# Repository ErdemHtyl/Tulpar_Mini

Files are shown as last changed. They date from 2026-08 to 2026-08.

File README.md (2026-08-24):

# MiniTULPAR — Custom Flight Controller Board (FCB)

> A quadcopter flight controller designed from scratch around the STM32F405.
> Schematic, 4-layer PCB, power architecture, sensor integration and firmware
> all live in this repository — no existing open-source flight controller is
> used.

<p align="left">
  
  
  
  
  
</p>

---

## ⚠️ Project Status

This project is **under active development**. The table below shows what is
finished and what is still in progress:

| Component | Status | Notes |
|---|---|---|
| Schematic design | ✅ Rev A complete | `MiniTulpar_Schematic.pdf` |
| PCB layout (4 layer) | ✅ Complete | 53.6 × 53.6 mm, 1.6 mm |
| Manufacturing files (Gerber/BOM/CPL) | ✅ Generated | `mfr/` |
| System architecture documentation | ✅ Complete | `docs/architecture.md` |
| Pin configuration (CubeMX) | ✅ Verified | No timer channel conflicts |
| Clock tree configuration | ✅ Verified | 168 MHz SYSCLK, 48 MHz USB |
| Board fabrication and assembly | 🔄 Planned | — |
| **Firmware** | 🚧 **In development — not started** | See the roadmap below |
| Flight testing | ⏳ Blocked | Depends on firmware |
| Lower-cost board variants | 🔄 Planned | See [Planned Variants](#planned-variants) |

> **Firmware note:** the firmware is **in development**. Nothing described in
> the roadmap below has been implemented yet — drivers, sensor fusion, PID
> control and the safety layer are all still to be written. The architectural
> decisions behind them (bus allocation, timer/DMA assignments, interrupt
> priorities) are documented in advance in `docs/architecture.md`, and
> development will follow that document. **The board does not fly in its
> current state.**

---

## Table of Contents

- [Project Goal](#project-goal)
- [Hardware Overview](#hardware-overview)
- [System Architecture](#system-architecture)
- [Bus Allocation and Rationale](#bus-allocation-and-rationale)
- [Timer and DMA Allocation](#timer-and-dma-allocation)
- [Pin Map](#pin-map)
- [Clock Configuration](#clock-configuration)
- [Firmware Roadmap](#firmware-roadmap)
- [Planned Variants](#planned-variants)
- [Repository Layout](#repository-layout)
- [Development Environment](#development-environment)
- [Known Issues and Rev B Notes](#known-issues-and-rev-b-notes)
- [License](#license)

---

## Project Goal

The goal is to **design, understand and implement every hardware and software
component** rather than buying an off-the-shelf flight controller (Betaflight /
ArduPilot hardware). That includes:

- Multi-layer PCB design and power architecture
- Writing IMU / barometer / magnetometer drivers from scratch
- Sensor fusion (Mahony / Madgwick / EKF)
- PID-based stabilisation and mixing
- Generating the DShot ESC protocol directly from timers and DMA
- GPS, telemetry, blackbox logging and the failsafe/safety layer

Every design decision is recorded in `docs/architecture.md` together with the
alternative that was rejected and the reason it was rejected.

---

## Hardware Overview

| Feature | Value |
|---|---|
| MCU | **STM32F405RGT6** — Cortex-M4F, 168 MHz, 1 MB Flash, 192 KB RAM (128 KB SRAM + 64 KB CCM) |
| Oscillator | 8 MHz HSE (ECS-80-10-30B-CKM-TR) |
| PCB | 4 layer, 53.6 × 53.6 mm, 1.6 mm thickness |
| Power | USB-C 5 V ↔ VIN, Schottky OR (D2/D3) + JP1 jumper → **LD39200PU33R** 3.3 V / 2 A LDO |
| IMU | **ICM-42670-P** (accel + gyro) — SPI1 @ 21 MHz, INT1 → PC4 |
| Barometer | **BMP581** — I2C2, 0x46, INT → PB1 |
| Magnetometer | **IIS2MDC** — I2C2, 0x1E, DRDY → PB2 |
| Blackbox flash | **W25Q128JVS** 16 MB — SPI2 @ 21 MHz |
| Motor outputs | 4× **DShot600** — TIM8_CH1..CH4 (PC6–PC9), single DMA burst |
| Auxiliary PWM | TIM1_CH1/CH3 (PA8/PA10) + TIM3_CH1/CH2 (PB4/PB5 — camera gimbal) |
| RC input | CRSF / ELRS — UART4 (J10) |
| GPS | USART2 (J12) |
| Telemetry | UART5 (J11) |
| Spare UART | USART3 (J5) |
| External I²C | I2C1 (J6) — separate from the internal sensor bus |
| ADC | Battery voltage → PC3 (ADC1_IN13), external → PC2 (ADC1_IN12) |
| USB | USB-C 2.0, USBLC6-2SC6 ESD protection + polyfuse + 5.1 kΩ CC |
| Debug | 10-pin 1.27 mm SWD (J13) |
| LEDs | 3× status LEDs + power LED |

---

## System Architecture

```mermaid
flowchart TB
    subgraph PWR["Power Tree"]
        XT[["VIN / Rail"]]
        USB5[["USB-C 5 V"]]
        OR{{"D2 / D3 Schottky OR<br/>+ JP1"}}
        LDO["U1 LD39200PU33R<br/>3.3 V / 2 A"]
        XT --> OR
        USB5 --> OR
        OR --> LDO
        LDO --> V33[("+3.3 V")]
        LDO -. "FB1 600Ω@100MHz" .-> VDDA[("VDDA")]
    end

    subgraph MCU["STM32F405RGT6 @ 168 MHz"]
        CORE["Cortex-M4F<br/>FPU + DSP"]
    end

    subgraph FAST["High rate — SPI1 @ 21 MHz"]
        IMU["U2 ICM-42670-P<br/>CS = PA4 · INT1 → PC4"]
    end

    subgraph SLOW["Slow sensor bus — I2C2 @ 400 kHz"]
        BARO["U4 BMP581 · 0x46"]
        MAG["U6 IIS2MDC · 0x1E"]
    end

    subgraph LOG["Logging — SPI2 @ 21 MHz"]
        FLASH["U7 W25Q128JVS<br/>16 MB · CS = PB12"]
    end

    subgraph ACT["Actuators"]
        ESC["4× ESC · DShot600<br/>TIM8_CH1..CH4"]
        SERVO["Aux PWM · TIM1 / TIM3"]
    end

    subgraph COMM["Serial links"]
        RC["CRSF/RC · UART4"]
        GPS["GPS · USART2"]
        TLM["Telemetry · UART5"]
        AUX["Spare · USART3"]
        EXTI2C["External I2C1"]
    end

    V33 --> MCU
    IMU <-->|SPI1| CORE
    BARO <-->|I2C2| CORE
    MAG <-->|I2C2| CORE
    FLASH <-->|SPI2| CORE
    CORE --> ESC
    CORE --> SERVO
    RC <--> CORE
    GPS <--> CORE
    TLM <--> CORE
    AUX <--> CORE
    EXTI2C <--> CORE
```

**The critical data path:** the IMU's INT1 line raises an EXTI interrupt → a
SPI1 DMA burst read starts → the DMA completion interrupt runs the filter, PID
and mixer chain → the result is encoded into a DShot frame and handed to the
TIM8 DMA. The whole chain completes **inside one interrupt context**, never
waiting on any other peripheral.

---

## Bus Allocation and Rationale

The founding principle of the architecture:

> **The critical path lives on SPI. Everything non-critical lives on I²C.**

| Device | Bus | Speed | Why |
|---|---|---|---|
| ICM-42670-P | **SPI1** (alone) | 21 MHz | The only high-rate path; the same read takes ~68× longer on I²C |
| BMP581 + IIS2MDC | **I2C2** (shared) | 400 kHz | ~4 % combined bus load; neither is on the critical path |
| W25Q128JVS | **SPI2** (alone) | 21 MHz | A sector erase can take 400 ms and must never delay a gyro read |
| External devices | **I2C1** | 400 kHz | A cable means ESD, capacitance and lockup risk — isolated from the internal sensors |

**Why the IMU is on SPI.** A 15-byte sample read takes ~5.7 µs on SPI1 versus
~388 µs on I²C Fast-mode:

| Loop rate | SPI load | I²C load |
|---|---|---|
| 1 kHz | 0.6 % | 39 % |
| 1.6 kHz | 0.9 % | 62 % |
| 4 kHz | 2.3 % | impossible |

Beyond bandwidth: SPI is deterministic (no clock stretching), has no bus-lockup
failure mode, survives the noisy environment of ESCs switching at 20–40 kHz
thanks to its push-pull drivers, and costs the CPU nothing when paired with DMA.

---

## Timer and DMA Allocation

### Timer assignment

The current CubeMX pin configuration is **conflict-free** — all four motor
outputs, both auxiliary PWM channels and both gimbal channels are usable at the
same time:

| Function | Timer | Channel | Pin | Timer clock |
|---|---|---|---|---|
| Motor 1–4 | **TIM8** | CH1–CH4 | PC6 / PC7 / PC8 / PC9 | 168 MHz (APB2) |
| Aux PWM 1–2 | TIM1 | CH1 / CH3 | PA8 / PA10 | 168 MHz (APB2) |
| Camera gimbal 1–2 | TIM3 | CH2 / CH1 | PB5 / PB4 | 84 MHz (APB1) |

The motors are on **TIM8** rather than TIM3 for four reasons:

1. TIM3_CH1 can be routed to either PC6 or PB4, but only one at a time — putting
   the motors on TIM8 leaves TIM3 entirely free for the gimbal outputs.
2. TIM8 sits on APB2, so its timer clock is 168 MHz (twice TIM3's) — twice the
   DShot bit-timing resolution.
3. TIM8 is an advanced-control timer: its break input can drive a hardware motor
   cutoff for failsafe later.
4. All four motors on one timer are bit-synchronous and need only a single DMA
   burst (TIM8_UP + DMAR).

Because the two gimbal channels sit on TIM3 (84 MHz) and the aux PWM channels on
TIM1 (168 MHz), driving both at a common servo rate means programming the two
timers separately with different prescaler values.

### DShot600 timing (TIM8 @ 168 MHz)

| Protocol | ARR | CCR for "0" | CCR for "1" | Frame |
|---|---|---|---|---|
| DShot300 | 559 | 210 | 420 | 53.3 µs |
| **DShot600** | **279** | **105** | **210** | **26.7 µs** |

DShot is digital: **ESC calibration stops being a step that exists**, and every
frame carries a 4-bit CRC — a command corrupted by noise is discarded by the ESC
instead of silently applying the wrong throttle.

### DMA assignments (under the RM0090 Table 42/43 constraints)

**DMA2**

| Stream | Ch | Assignment |
|---|---|---|
| S0 | 3 | SPI1_RX — IMU read *(the critical path)* |
| S1 | 7 | TIM8_UP — DShot burst output |
| S5 | 3 | SPI1_TX — IMU command |
| S2/S3/S4/S7 | 7 | *Reserved:* bidirectional DShot (unused in v1) |

**DMA1**

| Stream | Ch | Assignment |
|---|---|---|
| S0 | 4 | UART5_RX — telemetry |
| S1 | 4 | USART3_RX — spare |
| S2 | 4 | UART4_RX — CRSF/RC *(420 kbaud, critical)* |
| S3 | 0 | SPI2_RX — flash |
| S4 | 0 | SPI2_TX — blackbox |
| S5 | 4 | USART2_RX — GPS (circular + IDLE) |
| S6 | 4 | USART2_TX — GPS configuration |
| S7 | 4 | UART5_TX — telemetry |

I2C1/I2C2, UART4_TX, USART3_TX and ADC1 are interrupt-driven — their streams
went to higher-value work and their load is negligible.

### Interrupt priorities (NVIC)

| Priority | Interrupt |
|---|---|
| 0 | EXTI4 — IMU INT1 (timestamps the sampling instant) |
| 1 | DMA2_S0 — SPI1_RX complete (triggers the control chain) |
| 2 | DMA2_S1 — TIM8_UP (motor frame) |
| 3 | DMA1_S2 — UART4_RX (RC / failsafe) |
| 4 | DMA1_S5 — USART2_RX (GPS) |
| 5 | I2C2_EV / I2C2_ER |
| 6 | SysTick |
| 7 | Flash, UART5, USB |

> **The rule:** blackbox writes, USB and telemetry must **never** preempt the
> control loop.

### Target timing budget (1 kHz loop)

| Step | Duration | Occupies the CPU? |
|---|---|---|
| IMU SPI burst read | 5.7 µs | No (DMA) |
| Filtering (3× biquad + PT1) | ~10 µs | Yes |
| Attitude update (Mahony) | ~20 µs | Yes |
| PID (3 axes) | ~12 µs | Yes |
| Mixer + motor limiting | ~4 µs | Yes |
| DShot frame encoding | ~6 µs | Yes |
| **Total CPU** | **~52 µs** | **≈ 5 % load** |

---

## Pin Map

This table is the single source of truth for the pin map — it is never
maintained in two places.

| Port | Signal | Function |
|---|---|---|
| PA4 / PA5 / PA6 / PA7 | SPI1 CS/SCK/MISO/MOSI | IMU |
| PC4 | INT_IMU1 | EXTI4 — data ready |
| PB12 / PB13 / PB14 / PB15 | SPI2 CS/SCK/MISO/MOSI | Blackbox flash |
| PB10 / PB11 | I2C2 SCL/SDA | Internal sensor bus |
| PB1 / PB2 | INT_BAR / INT_MAG | EXTI1 / EXTI2 |
| PB8 / PB9 | I2C1 SCL/SDA | External connector (J6) |
| PC6 / PC7 / PC8 / PC9 | DSHOT_1..4 | **TIM8_CH1..CH4** |
| PA8 / PA10 | Aux PWM 1–2 | TIM1_CH1 / TIM1_CH3 |
| PB4 / PB5 | CAM_GIMBAL2 / CAM_GIMBAL1 | TIM3_CH1 / TIM3_CH2 |
| PA0 / PA1 | UART4 TX/RX | CRSF / RC (J10) |
| PA2 / PA3 | USART2 TX/RX | GPS (J12) |
| PC12 / PD2 | UART5 TX/RX | Telemetry (J11) |
| PC10 / PC11 | USART3 TX/RX | Spare (J5) |
| PC2 / PC3 | ADC1_IN12 / ADC1_IN13 | External ADC / battery |
| PA11 / PA12 / PA9 | USB DM/DP/VBUS | USB-C |
| PA13 / PA14 | SWDIO / SWCLK | SWD (J13) |
| PC13 / PC14 / PC15 | LD1 / LD2 / LD3 | Status LEDs |
| PH0 / PH1 | HSE IN/OUT | 8 MHz crystal |

**Unused and available:** PA15, PB0, PB3, PB6, PB7, PC0, PC1, PC5.
PB6/PB7 = USART1, PB0/PB1 = TIM3_CH3/CH4, and PB0 + PC5 together are exactly the
chip select + interrupt pair a second IMU would need.

Full pin table including physical pin numbers: [`docs/architecture.md`](docs/architecture.md)

---

## Clock Configuration

8 MHz HSE crystal → PLL (M = 4, N = 168, P = 2) → **168 MHz SYSCLK**, with the
PLL Q divider set to 7 for the 48 MHz USB clock. CSS (clock security system) is
enabled, so a crystal failure falls back to the HSI instead of stopping the
core.

| Domain | Prescaler | Frequency |
|---|---|---|
| SYSCLK / HCLK (AHB, core, memory, DMA) | /1 | **168 MHz** |
| APB1 peripheral clock (PCLK1) | /4 | 42 MHz |
| APB1 timer clock (TIM3 …) | — | 84 MHz |
| APB2 peripheral clock (PCLK2) | /2 | 84 MHz |
| APB2 timer clock (**TIM1, TIM8**) | — | **168 MHz** |
| USB OTG FS | PLL /Q = 7 | 48 MHz |
| IWDG | LSI | 32 kHz |

The RTC runs from the internal LSI — no LSE crystal is fitted, because PC14/PC15
are used as status LED outputs. This is irrelevant for a flight controller.

SPI1 and SPI2 both run at 21 MHz: SPI1 from PCLK2 (84 MHz ÷ 4) and SPI2 from
PCLK1 (42 MHz ÷ 2), both comfortably under the ICM-42670-P's 24 MHz and the
W25Q128's 133 MHz limits.

---

## Firmware Roadmap

> 🚧 **Nothing in this section has been implemented yet.** The order is chosen to
> minimise bring-up risk; each step depends on the previous one being verified.

### Stage 0 — Bring-up
- [ ] Project skeleton and build system
- [ ] SWD connection and LED blink — is the board alive?
- [ ] Bring up the clock tree on hardware and measure it (8 MHz HSE → 168 MHz)
- [ ] Generate the pin configuration from the pin map above
- [ ] Debug console over USB CDC

### Stage 1 — Sensors
- [ ] SPI1 + DMA driver, ICM-42670-P WHO_AM_I
- [ ] Raw IMU reads (INT1 → EXTI → DMA burst chain)
- [ ] IMU internal UI filter / ODR configuration *(anti-aliasing is critical)*
- [ ] I2C2 as a **non-blocking state machine** + timeouts + bus recovery (9× SCL)
- [ ] BMP581 driver (pressure → altitude)
- [ ] IIS2MDC driver + hard/soft-iron calibration
- [ ] Gyro/accel calibration and temperature compensation

### Stage 2 — Actuators
- [ ] DShot600 frame generation via TIM8 + DMAR burst
- [ ] Motor test mode — **props off**, verify frames on a scope
- [ ] Mixer (quad X), motor limiting / airmode

### Stage 3 — Control
- [ ] Gyro filter chain (biquad LPF + notch + PT1)
- [ ] Attitude estimation — Mahony (EKF later)
- [ ] Rate PID loop (acro mode)
- [ ] Angle/horizon loop (self-level)
- [ ] PID gain tuning interface

### Stage 4 — RC and safety
- [ ] CRSF parser (UART4 DMA + IDLE line)
- [ ] Arming/disarming state machine + sensor health check
- [ ] **IWDG** (~50 ms, fed only by the main control loop)
- [ ] Gyro timeout → immediate disarm
- [ ] RC timeout (~500 ms) → progressive throttle-cut failsafe
- [ ] Battery voltage monitoring + low-voltage warning

### Stage 5 — Navigation and logging
- [ ] GPS UBX/NMEA parser (USART2 DMA)
- [ ] Blackbox logging (SPI2 → W25Q128, pre-erase while idle)
- [ ] Telemetry (UART5) and the CRSF back-channel
- [ ] Altitude hold → position hold → return-to-home

### Stage 6 — Advanced
- [ ] Bidirectional DShot (RPM telemetry) + RPM-based notch filtering
- [ ] EKF-based sensor fusion
- [ ] Host-side unit tests (HIL/SIL)

**The safety layer is non-negotiable:** motors are **always** disarmed at
power-up; arming requires low throttle plus an explicit arm command plus a
sensor health check.

---

## Planned Variants

MiniTULPAR Rev A is the reference design — it is deliberately built with
good parts rather than cheap ones, so that when something misbehaves the cause
is the design and not the bill of materials.

**More affordable versions of this board will be added later.** The plan is to
publish lower-cost variants alongside the reference design, so the project stays
buildable on a smaller budget:

- Cheaper sensor options (a lower-cost IMU and barometer in place of the
  ICM-42670-P / BMP581)
- A reduced-feature build — dropping the blackbox flash, the magnetometer or the
  gimbal outputs where they are not needed
- Widely stocked, low-cost alternatives for the passives, connectors and the
  regulator
- Where a substitution changes the firmware, the difference will be documented
  rather than hidden behind a build flag

Each variant will ship with its own BOM and a short note on what was traded
away. The reference design stays the one that is documented and tested first.

---

## Repository Layout

Hardware and firmware live in a **single repository** (monorepo) — when a pin
changes, KiCad, the documentation and the firmware are all updated in the same
commit.

```
custom-fcb/
├── README.md
├── docs/                    architecture, power tree, pinout, BOM, test plan
│   ├── architecture.md      design decisions and their rationale (EN)
│   └── images/
├── hardware/
│   ├── MiniTULPAR.kicad_pro / .kicad_sch / .kicad_pcb
│   ├── libs/                custom symbol + footprint libraries
│   ├── datasheets/
│   └── production/          Gerber / drill / BOM / CPL — gitignored
└── firmware/                🚧 in development — nothing implemented yet
    ├── drivers/             imu, baro, mag, gps, crsf, esc/dshot
    ├── fusion/              mahony / madgwick / ekf
    ├── control/             pid, rate and angle loops, mixer
    ├── telemetry/
    ├── safety/              failsafe, arming, watchdog
    └── tests/               host-side unit tests
```

**Version control rules**

- `hardware/production/` is gitignored. Gerbers are added by hand only when a
  board is ordered, together with `git tag hw-vX.Y` — so it is always certain
  which board was built from which files.
- Flight logs (`logs/`, `*.bbl`) never enter the repository.
- `.gitattributes` normalises line endings to LF in the repository.

---

## Development Environment

**Hardware side**

| Tool | Version / note |
|---|---|
| KiCad | 8.x |
| Schematic | `MiniTULPAR.kicad_sch` (+ `scheme_diagram.kicad_sch`) |
| Custom footprints | `ftp.pretty/` |
| Custom symbols | `MiniTULPAR_sym.kicad_sym` |

**Firmware side** *(planned)*

| Tool | Note |
|---|---|
| Toolchain | `arm-none-eabi-gcc` |
| Build | CMake + Ninja |
| Peripheral layer | STM32CubeF4 (mostly LL; register level on the critical path) |
| Pin & clock configuration | STM32CubeMX |
| Debug | ST-Link / J-Link + OpenOCD, SWO trace |
| Measurement | Loop-time profiling with the DWT cycle counter |

**Ordering a board**

```powershell
git tag -a hw-v0.1 -m "First board order"
git push --tags
gh release create hw-v0.1 hardware\production\*.zip
```

---

## Known Issues and Rev B Notes

Findings from the schematic review. **None of them makes the board
non-functional**, but they should be decided before fabrication.

| # | Issue | Status / recommendation |
|---|---|---|
| 1 | **ICM-42670-P ODR ceiling of 1.6 kHz** — this is the low-power member of the family, not the ICM-42688-P. An 8 kHz loop is **not possible** on this board (sensor-limited, not bus-limited). | Target a **1 kHz PID loop**. Because of the aliasing risk, the internal UI filter must be configured deliberately and the IMU soft-mounted. |
| 2 | **The battery divider is off-board**, with no overvoltage protection. | Rev B: 1 kΩ series into PC3 plus a Schottky clamp to 3.3 V. |
| 3 | **LDO thermal budget** — 0.85 W at 500 mA with 5 V in. J5/J6/J7/J10/J11/J12 all supply 3.3 V, and a GPS module alone can draw 100–150 mA. | Thermal via array under the LDO; the load budget belongs in `docs/power-tree.md`. |
| 4 | **DShot pins after reset** are high-impedance. | Confirm the ESCs do not apply throttle in that state; add pull-downs on the motor lines if they do (Rev B). |

---

## License

**BSD 3-Clause License** — Copyright © 2026 Erdem Hatayoğlu.

One licence covers the whole repository: firmware, hardware design files and
documentation. It is permissive — you may use, modify and redistribute this
work in source and binary form, including commercially and in closed-source
products, provided that:

- the copyright notice, the list of conditions and the disclaimer are retained
- neither the project name nor the author's name is used to endorse or promote
  derived products without prior written permission

The work comes with no warranty of any kind. Full text: [`LICENSE`](LICENSE)

New files should carry an SPDX header so each file's licence is unambiguous:

```
SPDX-License-Identifier: BSD-3-Clause
SPDX-FileCopyrightText: 2026 Erdem Hatayoğlu
```

Third-party files (vendor headers, generated peripheral libraries, imported
footprints) keep the licence of their original author; where such a file carries
its own licence header, that header takes precedence.

---

## Disclaimer

This board and its firmware are **in development and untested**. Spinning
propellers can cause serious injury. Always run motor tests **with the
propellers removed**, perform the first closed-loop attempts on a safe test
bench, and verify the arming and failsafe logic before flying. Use this project
entirely at your own risk.

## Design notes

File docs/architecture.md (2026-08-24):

# MiniTULPAR — System Architecture and Design Rationale

**Board:** MiniTULPAR FCB · **Schematic revision:** Rev A (2026-08-10) + updated CubeMX pin configuration
**MCU:** STM32F405RGT6 (LQFP64, 168 MHz, 1 MB Flash, 192 KB RAM)
**Document status:** Derived from the Rev A schematic and the current CubeMX pinout; firmware decisions are proposals.
**Location:** `docs/architecture.md`

> This document does not record *what* was built — it records **why it was built
> this way**. Every decision lists the alternative that was rejected and the
> reason it was rejected. When the board is revised, this document gets revised
> too. If the schematic and this document ever disagree, **the schematic is
> right and this document is wrong** — fix the document.

---

## 0. Executive summary — the architecture in three sentences

A single ICM-42670-P IMU sits alone on **SPI1** and is sampled on a data-ready
interrupt; this is the only high-rate path on the board and it gets a bus to
itself. Slow sensors — barometer and magnetometer — share **I2C2**, because
their sampling rates cannot stress the bus and sharing buys back pins. All four
motors are driven from **TIM8** over DShot through a single DMA stream (TIM8_UP
with DMAR burst), and everything else flows through UART/DMA pairs that never
touch the CPU.

---

## 1. Block diagram

```mermaid
flowchart TB
    subgraph PWR["Power Tree"]
        XT[["Rail / XT60<br/>VCC"]]
        USB5[["USB-C 5 V"]]
        OR{{"D2 / D3 Schottky OR<br/>+ JP1 jumper"}}
        LDO["U1 LD39200PU33R<br/>3.3 V / 2 A LDO"]
        XT --> OR
        USB5 --> OR
        OR --> LDO
        LDO --> V33[("+3.3 V")]
        LDO -. "FB1 600Ω@100MHz" .-> VDDA[("VDDA")]
    end

    subgraph MCU["STM32F405RGT6 @ 168 MHz — HSE 8 MHz (X1)"]
        CORE["Cortex-M4F<br/>FPU + DSP"]
    end

    subgraph FAST["High rate — SPI1 @ 21 MHz"]
        IMU["U2 ICM-42670-P<br/>Accel + Gyro<br/>CS = PA4<br/>INT1 → PC4"]
    end

    subgraph SLOW["Slow sensor bus — I2C2 @ 400 kHz"]
        BARO["U4 BMP581<br/>0x46 · INT → PB1"]
        MAG["U6 IIS2MDC<br/>0x1E · DRDY → PB2"]
    end

    subgraph LOG["Logging — SPI2 @ 21 MHz"]
        FLASH["U7 W25Q128JVS<br/>16 MB · CS = PB12"]
    end

    subgraph ACT["Actuators"]
        ESC["4× ESC · DShot600<br/>TIM8_CH1..CH4<br/>PC6 PC7 PC8 PC9"]
        SERVO["Aux PWM<br/>TIM1_CH1/CH3 · PA8 PA10<br/>Gimbal · PB4 PB5 (TIM3)"]
    end

    subgraph COMM["Serial links"]
        RC["J10 CRSF/RC<br/>UART4 · PA0/PA1"]
        GPS["J12 GPS<br/>USART2 · PA2/PA3"]
        TLM["J11 Telemetry<br/>UART5 · PC12/PD2"]
        AUX["J5 Spare UART<br/>USART3 · PC10/PC11"]
        EXTI2C["J6 External I2C1<br/>PB8/PB9"]
    end

    subgraph MISC["Other"]
        ADCIN["J7 ADC → PC2<br/>J8 Battery → PC3"]
        SWD["J13 SWD<br/>PA13/PA14"]
        USBP["USB-C · PA11/PA12<br/>USBLC6-2SC6 ESD"]
        LEDS["LD1..LD3<br/>PC13/PC14/PC15"]
    end

    V33 --> MCU
    IMU <-->|SPI1| CORE
    BARO <-->|I2C2| CORE
    MAG <-->|I2C2| CORE
    FLASH <-->|SPI2| CORE
    CORE --> ESC
    CORE --> SERVO
    RC <--> CORE
    GPS <--> CORE
    TLM <--> CORE
    AUX <--> CORE
    EXTI2C <--> CORE
    ADCIN --> CORE
    SWD <--> CORE
    USBP <--> CORE
    CORE --> LEDS
```

**How data actually flows:** the IMU's INT1 line raises an EXTI interrupt → a
SPI1 DMA burst read starts → the DMA completion interrupt runs the filter, PID
and mixer chain → the result is encoded into a DShot frame and handed to the
TIM8 DMA. The whole chain completes **inside one interrupt context**, never
waiting on any other peripheral. Everything else — baro, mag, GPS, telemetry,
logging — runs outside that chain at lower priority.

### 1.1 Complete pin assignment

STM32F405RGT6, LQFP64. This table is the intended single source of truth — the
firmware's `board.h` should be derived from it, not maintained in parallel.

| Pin | Port | Signal | Peripheral / alternate function |
|---|---|---|---|
| 20 | PA4 | SPI1_CS1 | GPIO output — IMU chip select |
| 21 | PA5 | SPI1_SCK | SPI1 |
| 22 | PA6 | SPI1_MISO | SPI1 |
| 23 | PA7 | SPI1_MOSI | SPI1 |
| 24 | PC4 | INT_IMU1 | EXTI4 — IMU data ready |
| 33 | PB12 | SPI2_CS | GPIO output — flash chip select |
| 34 | PB13 | SPI2_SCK | SPI2 |
| 35 | PB14 | SPI2_MISO | SPI2 |
| 36 | PB15 | SPI2_MOSI | SPI2 |
| 29 | PB10 | I2C2_SCL | I2C2 — internal sensor bus |
| 30 | PB11 | I2C2_SDA | I2C2 |
| 27 | PB1 | INT_BAR | EXTI1 — BMP581 |
| 28 | PB2 | INT_MAG | EXTI2 — IIS2MDC DRDY |
| 61 | PB8 | I2C1_SCL | I2C1 — external connector |
| 62 | PB9 | I2C1_SDA | I2C1 |
| 37 | PC6 | DSHOT_1 | **TIM8_CH1** |
| 38 | PC7 | DSHOT_2 | **TIM8_CH2** |
| 39 | PC8 | DSHOT_3 | **TIM8_CH3** |
| 40 | PC9 | DSHOT_4 | **TIM8_CH4** |
| 41 | PA8 | Aux PWM 1 | TIM1_CH1 |
| 43 | PA10 | Aux PWM 2 | TIM1_CH3 |
| 57 | PB5 | CAM_GIMBAL1 | TIM3_CH2 |
| 56 | PB4 | CAM_GIMBAL2 | TIM3_CH1 |
| 14 | PA0 | UART4_TX | UART4 — CRSF / RC |
| 15 | PA1 | UART4_RX | UART4 |
| 16 | PA2 | USART2_TX | USART2 — GPS |
| 17 | PA3 | USART2_RX | USART2 |
| 51 | PC10 | USART3_TX | USART3 — spare |
| 52 | PC11 | USART3_RX | USART3 |
| 53 | PC12 | UART5_TX | UART5 — telemetry |
| 54 | PD2 | UART5_RX | UART5 |
| 10 | PC2 | ADC1 | ADC1_IN12 — external sense |
| 11 | PC3 | Battery_Voltage | ADC1_IN13 |
| 44 | PA11 | USB_OTG_FS_DM | USB |
| 45 | PA12 | USB_OTG_FS_DP | USB |
| 42 | PA9 | USB_OTG_FS_VBUS | USB VBUS detect |
| 46 | PA13 | SWDIO | SYS_JTMS-SWDIO |
| 49 | PA14 | SWCLK | SYS_JTCK-SWCLK |
| 2 | PC13 | LD1 | GPIO — see §6.7 ⚠ |
| 3 | PC14 | LD2 | GPIO — see §6.7 ⚠ |
| 4 | PC15 | LD3 | GPIO — see §6.7 ⚠ |
| 5 | PH0 | RCC_OSC_IN | HSE 8 MHz (X1) |
| 6 | PH1 | RCC_OSC_OUT | HSE |
| 7 | NRST | Reset | S1 button + 100 nF |
| 60 | BOOT0 | Boot select | S2 SPDT switch |
| 1 | VBAT | Backup supply | |
| 13 / 12 | VDDA / VSSA | Analog supply | FB1 + 0.1 µF + 1 µF |
| 31 / 47 | VCAP1 / VCAP2 | Core regulator | 2.2 µF each |
| 19, 32, 48, 64 | VDD | Digital supply | 100 nF per pin |
| 18, 63 | VSS | Ground | |

**Unused and available:** PA15 (50), PB0 (26), PB3 (55), PB6 (58), PB7 (59),
PC0 (8), PC1 (9), PC5 (25). Notable options among these: PB6/PB7 are USART1,
PB0/PB1 are TIM3_CH3/CH4, and PC0/PC1 are unrestricted GPIOs — see §6.7 for why
that last pair matters. Leave test points on all of them in the layout; it is
cheap insurance.

---

## 2. Bus allocation and rationale

### 2.1 Summary

| Sensor / device | Bus | Clock | Sample rate | Why this bus |
|---|---|---|---|---|
| ICM-42670-P (accel/gyro) | **SPI1**, CS = PA4 | 21 MHz | up to 1.6 kHz | The only high-rate path; I²C bandwidth does not fit (§2.2) |
| BMP581 (baro) | **I2C2** | 400 kHz | ~50–100 Hz | Slow; saves pins; not worth occupying an SPI |
| IIS2MDC (mag) | **I2C2** | 400 kHz | 100 Hz | Same; I²C is also the part's native interface |
| W25Q128JVS (log) | **SPI2** | 21 MHz | continuous block writes | Must not share a bus with the IMU (§2.4) |
| CRSF / RC | UART4 | 420 kbaud | 250–500 Hz packets | Framed protocol; DMA + IDLE line costs zero CPU |
| GPS | USART2 | 115200 | 5–10 Hz | Same |
| Telemetry | UART5 | 57600–115200 | ~10 Hz | Same |
| Spare | USART3 | — | — | ESC telemetry / VTX / future use |
| External I²C | I2C1 | 400 kHz | ≤100 Hz | Leaves the board on a cable — kept **separate** from the internal bus (§2.5) |
| Camera gimbal | TIM3_CH1/CH2 (PB4/PB5) | 50–333 Hz | — | Servo-rate PWM; deliberately *not* on TIM8 (§3.1) |

### 2.2 DECISION: the IMU goes on **SPI1**, not on I²C

**Decision:** the ICM-42670-P sits alone on SPI1 with a dedicated chip select
(PA4).

**Rationale — the numbers.** One sample read is 1 register address byte + 14
data bytes (TEMP 2 + GYRO 6 + ACCEL 6) = 15 bytes.

*On SPI1 (APB2 = 84 MHz, prescaler /4 → 21 MHz, below the ICM-42670-P's 24 MHz
limit):*

```
15 bytes × 8 bits = 120 bits
120 bits ÷ 21 MHz  ≈  5.7 µs
```

*The same read over I²C (Fast-mode, 400 kHz):*

```
START + ADDR_W(9) + REG(9) + REPEATED START + ADDR_R(9) + 14×9 bits + STOP
= 9 + 9 + 9 + 126  ≈  155 bit-times  (plus start/stop overhead)
155 ÷ 400 kHz  ≈  388 µs
```

**The same work takes roughly 68× longer on I²C.** What that costs:

| Loop rate | Period | SPI load | I²C load |
|---|---|---|---|
| 1 kHz | 1000 µs | 0.6 % | **39 %** |
| 1.6 kHz (the part's ceiling) | 625 µs | 0.9 % | **62 %** |
| 4 kHz | 250 µs | 2.3 % | **impossible** |
| 8 kHz | 125 µs | 4.6 % | **impossible** |

Because 388 µs > 125 µs, 8 kHz sampling physically does not fit on I²C — a
single read consumes three times the whole period. At 1.6 kHz it technically
"fits", but handing 62 % of a bus to one sensor means nothing else can ever
share that bus.

And there is no escape upward. The ICM-42670-P's own I²C interface is rated to
1 MHz, but **the STM32F405's I²C peripheral cannot exceed 400 kHz** — there is no
Fast-mode Plus on this MCU, so the sensor's headroom is unreachable. Even if it
were reachable, 155 bit-times at 1 MHz is 155 µs, still longer than a 125 µs
period: 8 kHz would not fit on I²C at *any* clock this pairing can produce.

(The SPI side has margin in hand by comparison: the part is rated to 24 MHz and
the chosen 21 MHz sits just under it, arrived at by the APB2 ÷ 4 prescaler
rather than by pushing the sensor.)

**The reasons that have nothing to do with bandwidth — these matter just as
much:**

1. **Determinism.** An SPI transfer takes a fixed, predictable time. On I²C a
   slave may apply **clock stretching**, so the transfer takes as long as the
   slave feels like. Jitter in the control loop period shows up directly as
   noise on the derivative term.
2. **Bus lockup.** I²C is open-drain. If a slave resets at the wrong moment it
   can hold SDA low and **wedge the entire bus**. Recovery means manually
   clocking out nine SCL pulses — not something to be doing mid-flight. SPI has
   no equivalent failure mode; deasserting CS resynchronises the device.
3. **Noise immunity.** The ESCs switch tens of amps at 20–40 kHz. I²C's slow,
   pull-up-driven rising edges are vulnerable in that environment; SPI's
   push-pull drivers are far more robust.
4. **STM32F4 I²C errata.** The F4 family's I²C peripheral has documented errata,
   including a BUSY flag that can latch under specific conditions. The
   flight-critical path should not be built on that peripheral.
5. **DMA friendliness.** SPI + DMA moves 15 bytes at **zero** CPU cost. I²C +
   DMA works on the F4, but the START/ADDR/RESTART phases still need interrupt
   servicing — it is not free.

**Rejected alternatives:**

- *IMU on I²C* — see the table above. This would be reasonable for a 100 Hz tilt
  sensor. It is not reasonable for a flight controller.
- *Sharing one SPI between the IMU and the flash* — see §2.4.
- *Polling instead of using the INT line* — the delay between the sampling
  instant and the read instant becomes variable, which is a timestamp error in
  the fusion filter. This is exactly why INT1 is routed to PC4, and it
  **must be used**.

### 2.3 DECISION: barometer and magnetometer share **I2C2**

**Decision:** BMP581 (0x46) and IIS2MDC (0x1E) share I2C2 on PB10/PB11.

**Rationale.** The physics of these sensors is already slow.

- Barometer: altitude estimation gains nothing above 50–100 Hz — measurement
  noise and the sensor's own conversion time dominate.
- Magnetometer: the IIS2MDC tops out at 100 Hz ODR, so reading faster buys
  nothing.

Load calculation, with both sensors reading 6 bytes at 100 Hz:

```
6-byte read ≈ 9 + 9 + 9 + 54 = 81 bit-times ≈ 203 µs @ 400 kHz
2 sensors × 100 Hz × 203 µs = 40.6 ms/s  →  bus load ≈ 4 %
```

Four percent load, ninety-six percent idle. Moving these to SPI would spend two
more chip-select pins and gain nothing. **I²C's weaknesses — indeterminate
timing, lockup risk — are acceptable here**, because neither sensor is on the
critical path of the stabilisation loop. If the baro or mag stalls for a few
periods, or dies outright, the quad keeps flying with degraded altitude and
heading. If the gyro stalls, it falls. That asymmetry is the whole basis of the
split:

> **The critical path lives on SPI. Everything non-critical lives on I²C.**

**The obligation this puts on firmware:** the I2C2 driver must be written as a
**non-blocking state machine**, every transfer must have a timeout, and a
timeout must trigger the bus recovery routine (nine SCL pulses followed by a
STOP). A failure of these two sensors must never stall the main loop.

### 2.4 DECISION: flash on its own bus (SPI2), not shared with the IMU

**Decision:** the W25Q128JVS gets SPI2 (PB12–PB15) to itself.

**Rationale.** Blackbox logging writes **long and unpredictable** blocks by
nature:

| Operation | Duration (W25Q128JV typ / max) |
|---|---|
| 256-byte page program | 0.7 ms / 3 ms |
| 4 KB sector erase | 45 ms / 400 ms |

A sector erase can take **up to 400 ms**. If the flash shared a bus with the
IMU, a gyro read would sit behind that queue — or the firmware would need
elaborate transfer-splitting and priority logic. Two separate SPIs make the
problem disappear at design time: **no shared resource, no priority problem.**

Bandwidth check: at 1 kHz with ~60 bytes per record, logging produces 60 kB/s.
The flash sustains 256 B / 0.7 ms ≈ 365 kB/s — comfortable margin. The real
constraint is erase time:

```
Worst case: 400 ms erase × 60 kB/s = 24 KB of RAM buffering required
```

The F405's 192 KB (128 KB SRAM + 64 KB CCM) covers that easily, but **the buffer
size should not be left to chance**. The better approach is to erase ahead
during idle time — erase the next blocks before arming — so that only page
programs happen in flight and the required buffer drops to 3 ms × 60 kB/s ≈
200 bytes.

### 2.5 DECISION: two separate I²C buses — internal (I2C2) and external (I2C1)

**Decision:** on-board sensors on I2C2; the off-board J6 connector on its own
bus, I2C1 (PB8/PB9).

**Rationale.** The external bus leaves the board on a cable, which brings three
distinct risks:

1. **ESD and shorts.** A reversed connector or a chafed cable takes down
   everything on that bus. Isolating the internal baro and mag means one cable
   fault cannot kill altitude estimation.
2. **Lockup isolation.** If an external device — a GPS module's compass, say —
   holds SDA low and wedges its bus, the internal sensors are untouched.
3. **Capacitance and edge rates.** A cable adds roughly 50–100 pF per metre. On
   a shared bus that would degrade the internal sensors' edges too.

**A concrete finding that falls out of this:** the schematic pulls both buses up
with 4.7 kΩ (I2C1: R5/R6, I2C2: R3/R4). Fast-mode allows a maximum rise time of
300 ns:

```
t_r ≈ 0.8473 × R × C   →   C_max = 300 ns / (0.8473 × 4700 Ω) ≈ 75 pF
```

The internal bus — two devices, short traces — lands around 20–40 pF, so
**4.7 kΩ is fine there**. On the external bus, even 30 cm of cable adds 30–50 pF,
and together with the remote module the 75 pF budget is **exceeded**.
Recommendation: **drop the I2C1 pull-ups to 2.2 kΩ** (R5/R6). That allows about
160 pF instead of 75 pF, and the sink current stays at 3.3 V / 2.2 kΩ = 1.5 mA,
well under the 3 mA I²C limit.

---

## 3. Timer and DMA allocation

### 3.1 The TIM3 constraint — already resolved, do not undo it

The pins the board uses can each be reached by more than one timer, and two of
those options overlap:

| Net | Pin | Timer channels that can reach this pin |
|---|---|---|
| DSHOT_1 | PC6 | TIM3_CH1 · **TIM8_CH1** ← chosen |
| DSHOT_2 | PC7 | TIM3_CH2 · **TIM8_CH2** ← chosen |
| DSHOT_3 | PC8 | TIM3_CH3 · **TIM8_CH3** ← chosen |
| DSHOT_4 | PC9 | TIM3_CH4 · **TIM8_CH4** ← chosen |
| CAM_GIMBAL2 | PB4 | **TIM3_CH1** (only option) |
| CAM_GIMBAL1 | PB5 | **TIM3_CH2** (only option) |
| Aux PWM 1 | PA8 | **TIM1_CH1** (only option) |
| Aux PWM 2 | PA10 | **TIM1_CH3** (only option) |

**The latent conflict:** PB4 and PC6 are two alternate pins for the *same*
channel, TIM3_CH1 — and a timer channel can only be routed to **one pin at a
time**. Route DShot through TIM3 and the gimbal outputs go dead; route the
gimbal through TIM3 and DSHOT_1/DSHOT_2 go dead.

**The current CubeMX configuration assigns DShot to TIM8, which avoids this
entirely.** The gimbal keeps TIM3_CH1/CH2 and all four motor outputs work. This
section exists so that nobody "simplifies" the design later by moving DShot to
TIM3 — PC6–PC9 map to TIM3 just as naturally, the change looks harmless, and it
silently kills the gimbal outputs.

**The assignment to preserve:**

| Function | Timer | Channel | Pin | Timer clock |
|---|---|---|---|---|
| Motor 1 | **TIM8** | CH1 | PC6 | 168 MHz (APB2) |
| Motor 2 | **TIM8** | CH2 | PC7 | 168 MHz |
| Motor 3 | **TIM8** | CH3 | PC8 | 168 MHz |
| Motor 4 | **TIM8** | CH4 | PC9 | 168 MHz |
| Aux PWM 1 | TIM1 | CH1 | PA8 | 168 MHz (APB2) |
| Aux PWM 2 | TIM1 | CH3 | PA10 | 168 MHz |
| Camera gimbal 2 | TIM3 | CH1 | PB4 | 84 MHz (APB1) |
| Camera gimbal 1 | TIM3 | CH2 | PB5 | 84 MHz |

**Why TIM8 rather than TIM3:**

1. It resolves the conflict — all four aux PWM channels stay usable.
2. TIM8 lives on APB2, so its timer clock is **168 MHz** (TIM3 is on APB1 at
   84 MHz). That is twice the resolution for DShot bit timing (§3.2).
3. TIM8 is an advanced-control timer: it has dead-time generation, a break input
   and a repetition counter. The break input is a path to hardware motor cutoff
   for failsafe later; TIM3 has none of this.
4. All four motors on **one timer** means they are bit-synchronous, and one DMA
   stream (TIM8_UP + DMAR burst) drives all of them.

**Note:** the four servo-rate outputs are split across TIM1 (PA8, PA10) and TIM3
(PB4, PB5), so driving them at a common rate means programming both timers to
the same period (e.g. 50 Hz / 20 ms, or 333 Hz) separately — and the prescaler
values will differ, because TIM1 runs at 168 MHz and TIM3 at 84 MHz. For a
camera gimbal this is harmless; the two axes only need to agree with themselves.

### 3.2 DShot timing numbers (TIM8 @ 168 MHz)

DShot encodes a bit by pulse width: high for **37.5 %** of the bit period is a
"0", high for **75 %** is a "1". In PWM mode the CCR value changes per bit.

| Protocol | Bit rate | ARR | CCR for "0" | CCR for "1" | 16-bit frame |
|---|---|---|---|---|---|
| DShot150 | 150 kbit/s | 1119 | 420 | 840 | 107 µs |
| DShot300 | 300 kbit/s | 559 | 210 | 420 | 53.3 µs |
| **DShot600** | 600 kbit/s | **279** | **105** | **210** | **26.7 µs** |
| DShot1200 | 1200 kbit/s | 139 | 52 | 105 | 13.3 µs |

```
ARR = (168 MHz / bit_rate) − 1        →  168e6 / 600e3 − 1 = 279
CCR_0 = 0.375 × 280 = 105
CCR_1 = 0.750 × 280 = 210
```

**Recommendation: DShot600.** A 26.7 µs frame is 2.7 % of a 1 kHz period, 4.3 %
at 1.6 kHz. DShot1200 is fussy about cable length and ESC compatibility and buys
nothing here. DShot300 is a more forgiving first target; move to 600 once the
board is proven.

**Bidirectional DShot (RPM telemetry)**, if added later: the same pin is turned
into an input roughly 30 µs after the frame is sent, and the ESC's 21-bit GCR
response is read by input capture. That needs a separate DMA stream per channel
and changes the budget in §3.4 — handled there.

### 3.3 Why DShot rather than PWM or OneShot

| Protocol | Resolution | Frame | Calibration | CRC |
|---|---|---|---|---|
| PWM (1000–2000 µs) | ~1000 steps | 2 ms @ 500 Hz | Required | None |
| OneShot125 | ~1000 steps | 250 µs | Required | None |
| **DShot600** | **2048 steps** | **26.7 µs** | **Not needed** | **4-bit** |

DShot is digital: it does not depend on the ESC's interpretation of an analogue
pulse width, so **ESC calibration stops being a step that exists**. Every frame
carries a 4-bit CRC, so a command corrupted by noise gets discarded by the ESC
instead of silently applying the wrong throttle. On a noisy power board that
difference is a safety property, not a convenience.

### 3.4 DMA allocation

On the STM32F4, each peripheral request is hard-wired to **specific
stream + channel** combinations (RM0090 Tables 42/43). DMA allocation is
therefore not a free choice — it is a **constraint-satisfaction problem**. The
table below is a conflict-free solution under those constraints.

#### DMA2 (drives SPI1, TIM8, ADC1)

| Stream | Ch | Assignment | Why |
|---|---|---|---|
| **S0** | 3 | **SPI1_RX** — IMU read | The critical path. SPI1_RX exists only on S0C3 or S2C3 |
| **S1** | 7 | **TIM8_UP** — DShot burst output | The only option for TIM8_UP. DMAR writes CCR1–CCR4 in one go |
| **S2** | 7 | TIM8_CH1 (bidirectional DShot capture, M1) | Optional — §3.4.1 |
| **S3** | 7 | TIM8_CH2 (M2) | Optional |
| **S4** | 7 | TIM8_CH3 (M3) | Optional |
| **S5** | 3 | **SPI1_TX** — IMU command | SPI1_TX: S3C3 or S5C3. S3 was given to TIM8_CH2 |
| S6 | — | *free* | Reserve |
| **S7** | 7 | TIM8_CH4 (M4) | Optional |

#### DMA1 (drives SPI2, the UARTs, I²C)

| Stream | Ch | Assignment | Why |
|---|---|---|---|
| **S0** | 4 | **UART5_RX** — telemetry in | |
| **S1** | 4 | **USART3_RX** — spare UART | |
| **S2** | 4 | **UART4_RX** — CRSF / RC | **Critical.** 420 kbaud = 42 kB/s; interrupt-per-byte would mean 42 000 ISRs per second |
| **S3** | 0 | **SPI2_RX** — flash | |
| **S4** | 0 | **SPI2_TX** — flash / blackbox | Keeps long block writes off the CPU |
| **S5** | 4 | **USART2_RX** — GPS | Circular mode + IDLE line interrupt |
| **S6** | 4 | **USART2_TX** — GPS configuration (UBX) | |
| **S7** | 4 | **UART5_TX** — telemetry out | |

**What is left without DMA, and why:**

- **I2C1 and I2C2 → interrupt-driven.** I2C2_RX's options are S2C7 and S3C7, and
  both went to higher-value work (CRSF RX, flash RX). Acceptable: 6-byte
  transfers at 100 Hz produce ~1200 interrupts per second, about a thousandth of
  the CPU.
- **UART4_TX (CRSF telemetry back-channel) → interrupt.** Its S4C4 option
  collides with SPI2_TX. The back-channel is a few hundred bytes per second;
  interrupts are fine.
- **USART3_TX → interrupt.** Same reason (S3C4/S4C7 both collide).
- **ADC1 → interrupt or direct read.** ADC1's DMA options are DMA2 S0C0 and
  S4C0, both taken. Battery voltage and current are read at 100 Hz; a two-channel
  scan conversion serviced in an interrupt is negligible.

#### 3.4.1 The trade-off: bidirectional DShot or ADC DMA?

In the table above, DMA2 streams S2/S3/S4/S7 are reserved for bidirectional
DShot. **If bidirectional DShot is not used**, those four streams free up and
S0C0 or S4C0 opens for ADC1. The decision:

> **No bidirectional DShot on the first flight.** Run the ADC without DMA and
> leave the streams unused. RPM telemetry — for RPM-based notch filtering —
> comes later, in a separate firmware version, once basic flight is stable.

The reason: bidirectional DShot also requires support on the ESC side
(BLHeli_32 / AM32), GCR decoding is unpleasant to debug, and it muddies the
picture during bring-up. Get it flying first, then filter it.

### 3.5 Interrupt priority table (NVIC)

Allocating DMA and timers correctly is not enough; **which interrupt is allowed
to preempt which** is part of the architecture too. On Cortex-M4, lower number =
higher priority.

| Priority | Interrupt | Rationale |
|---|---|---|
| 0 | EXTI4 (PC4 — IMU INT1) | Timestamps the sampling instant. Any delay corrupts the timestamp |
| 1 | DMA2_Stream0 (SPI1_RX complete) | Triggers the control chain |
| 2 | DMA2_Stream1 (TIM8_UP) | Motor frame output |
| 3 | DMA1_Stream2 (UART4_RX — RC) | RC loss means failsafe; low tolerance for delay |
| 4 | DMA1_Stream5 (USART2_RX — GPS) | |
| 5 | I2C2_EV / I2C2_ER | Baro/mag; delay is harmless |
| 6 | SysTick | Timebase |
| 7 | DMA1_S3/S4 (flash), UART5, USB | None of these affect flight |

**The rule:** nothing runs at a higher priority than the interrupt that executes
the PID chain (priority 1). Blackbox writes, USB and telemetry must **never**
preempt the control loop.

---

## 4. Timing budget

The table below is an estimated budget for a 1 kHz control loop (1000 µs
period). These are targets — the real numbers should be measured with the DWT
cycle counter and written back into this table.

| Step | Duration | Occupies the CPU? |
|---|---|---|
| IMU SPI burst read | 5.7 µs | No (DMA) |
| Gyro/accel filtering (3× biquad + PT1) | ~10 µs | Yes |
| Attitude update (Mahony, 1 kHz) | ~20 µs | Yes |
| PID (3 axes, rate + angle) | ~12 µs | Yes |
| Mixer + motor limiting | ~4 µs | Yes |
| DShot frame encoding (4 channels × 16 bits) | ~6 µs | Yes |
| DShot600 frame transmission | 26.7 µs | No (DMA) |
| **Total CPU** | **~52 µs** | **5.2 % load** |

About 5 % core utilisation at 168 MHz leaves the remaining 95 % for the baro/mag
state machine, GPS parsing, telemetry, blackbox — and **margin for error**. That
margin is deliberate: the first firmware that actually works is always heavier
than the estimate.

---

## 5. Sampling architecture and the ODR ceiling

### 5.1 The ICM-42670-P's ODR ceiling

*Verified against the TDK ICM-42670-P datasheet (DS-000451), not from memory.*

**ODR — output data rate** — is the rate at which the sensor writes a *new*
number into its output registers. The IMU runs on its own internal clock: it
samples the MEMS structure, filters, decimates, and updates the registers at
this fixed rate. **The ICM-42670-P's ODR range is 12.5 Hz – 1600 Hz for the
gyroscope and 1.5625 Hz – 1600 Hz for the accelerometer.** 1.6 kHz is the
ceiling. This is the low-power member of the family — it is *not* the
ICM-42688-P, which reaches 32 kHz.

**Why the bus speed cannot rescue this.** At 1.6 kHz ODR the register contents
change once every 625 µs. Reading them faster returns the same value again:

```
t = 0   µs → read → 142.7 °/s   (new)
t = 125 µs → read → 142.7 °/s   ← identical
t = 250 µs → read → 142.7 °/s   ← identical
t = 375 µs → read → 142.7 °/s   ← identical
t = 500 µs → read → 142.7 °/s   ← identical
t = 625 µs → read → 148.1 °/s   (new)
```

An 8 kHz loop would execute 8000 times per second on 1600 distinct pieces of
information. The extra 6400 iterations add nothing — and they actively harm the
derivative term, which now sees a staircase: four periods of zero slope followed
by a step. That is the worst possible input to a D term.

**So the ceiling is set by the sensor, not by the bus.** The SPI decision in
§2.2 remains correct — I²C would consume 62 % of the bus even at 1.6 kHz — but
the second half of the argument ("8 kHz does not fit on I²C") never gets
exercised on this board, because 8 kHz is unreachable anyway.

**What a 1.6 kHz ODR would normally cost you — and why it does not here.** By
Nyquist, a 1.6 kHz sample rate can faithfully represent content only up to
800 Hz. Anything above that would normally fold back and appear at the wrong
frequency. For a 5-inch quad at 25 000 rpm the arithmetic looks alarming:

| Vibration component | True frequency | Would alias to, at 1.6 kHz |
|---|---|---|
| Fundamental (25000/60) | 417 Hz | 417 Hz — in band, correct |
| 2nd harmonic | 833 Hz | 767 Hz — wrong place |
| **3rd harmonic** | **1250 Hz** | **350 Hz** — indistinguishable from real motion |

That third row is the classic failure: a 1250 Hz mechanical vibration would
present itself to the gyro as a genuine 350 Hz rotation, the PID would chase it,
and the motors would heat up while the aircraft fought itself.

**The datasheet resolves this in the part's favour.** The ICM-42670-P's signal
path is: ADC → **anti-alias filter (AAF)** → programmable 1st-order low-pass →
ODR decimation. The AAF has fixed coefficients, is **not user-configurable and
cannot be bypassed**, and it sits ahead of decimation — which is exactly where
it needs to be. The aliasing scenario above is therefore handled in silicon, not
left to you.

**One condition attached, and it is the actionable part:** the datasheet
describes the AAF as active in **Low-Noise Mode**. Low-Power Mode is a different
signal path. So:

> **Run the gyro in Low-Noise Mode.** This is not a performance preference — it
> is what keeps the anti-alias filter in the path. Do not let a power-saving
> change quietly move the part into Low-Power Mode.

**The architectural consequences:**

1. **An 8 kHz control loop is not possible on this board** — sensor-limited, not
   bus-limited. The SPI decision stands regardless; it is just that the
   8 kHz half of the argument never gets exercised here.
2. **Target a 1 kHz PID loop**, gyro sampled at 1.6 kHz ODR. This is not a
   concession: ArduPilot and PX4 have flown 400 Hz–1 kHz loops for years.
   Betaflight's 8 kHz exists for racing feel and RPM-based filtering, neither of
   which is a first-board requirement.
3. **Set `GYRO_UI_FILT_BW` deliberately** — the programmable low-pass after the
   AAF is yours to choose, and its reset default is not a design decision.
4. **Still soft-mount the IMU.** The AAF prevents high-frequency energy from
   *aliasing*, but it does not prevent it from saturating the sensor or from
   consuming dynamic range. Keeping vibration out mechanically remains the
   cheapest filter on the aircraft.
5. **The FIFO is available if wanted:** 2.25 KB total, of which 1 KB is
   allocated to the FIFO by default (the rest is reserved for the APEX motion
   features, and can be reclaimed by disabling them). Not needed for a
   straightforward interrupt-per-sample design, but it is there if batching ever
   becomes useful.

**Recommendation:** target 1 kHz with this board — the architecture is sound and
the learning value is intact. If Rev B wants a higher loop rate, the
**ICM-42688-P** is the upgrade; it is in the same 14-pin LGA 2.5 × 3.0 mm class,
but the **pin map is not identical**, so the footprint and schematic must be
checked against the datasheet.

### 5.2 Interrupt-driven sampling, not polling

INT1 is routed to PC4 — use it:

```
IMU INT1 (PC4) → EXTI4 → start SPI1 DMA burst read
                          ↓
                 DMA2_S0 TC ISR → filter → PID → mixer → DShot DMA
```

This makes the delay between the sampling instant and the use of that data
**constant**. With periodic timer polling, the sensor's internal ODR clock and
the MCU clock drift against each other, so occasionally the same sample gets
read twice or one gets skipped — a silent and very hard-to-diagnose error source
in sensor fusion.

**INT2 (pin 9) is unconnected in the schematic.** It may be wanted later for a
FIFO watermark interrupt; for now one INT line is sufficient.

---

## 6. Findings from the schematic review

These came out of reading Rev A against the current pin configuration. None of
them makes the board non-functional.

### 6.1 Block diagram sheet vs schematic — ✅ resolved

The Rev A block diagram sheet disagreed with the schematic on the barometer part
number, the IMU count and the bus quantities. This has been corrected. Keep the
habit: whenever the schematic changes, the block diagram sheet changes in the
same commit, or the two drift apart again.

### 6.2 TIM3 channel conflict — ✅ avoided by design

The latent conflict between DShot and the gimbal outputs over TIM3_CH1/CH2 is
documented in §3.1. The current configuration puts DShot on **TIM8**, which
avoids it. Record this in `docs/pinout.md` as a constraint, not a preference —
the failure mode if someone moves DShot to TIM3 later is silent.

### 6.3 Magnetometer placement

The IIS2MDC is on-board. The magnetometer is the sensor most affected by the
magnetic field that motor currents produce, and a few millimetres from a 30 A
power trace it is not measuring the Earth's field — it is measuring throttle
position.

**Recommendation:** keep the IIS2MDC as a backup and use the GPS module's
compass over **J6 (external I2C1)** as the primary. In the PCB layout, put the
IIS2MDC as far from the power section as the board allows, ideally in the
opposite corner. Also plan a calibration step that measures compass deviation
against throttle.

### 6.4 3.3 V LDO thermal budget

The LD39200PU33R can supply 2 A, but everything dropped across an LDO becomes
heat:

```
P = (V_in − 3.3 V) × I_load
At 5 V in:  1.7 V × I
```

Load estimate: MCU ~60 mA + sensors ~5 mA + flash ~15 mA (while writing) +
whatever the connectors feed. **The important part:** J5, J6, J7, J10, J11 and
J12 all supply +3.3 V, and a GPS module alone can draw 100–150 mA.

| Total load | Dissipated in the LDO (5 V in) |
|---|---|
| 100 mA | 0.17 W — fine |
| 300 mA | 0.51 W — watch it |
| 500 mA | **0.85 W** — needs thermal vias and copper pour under the DFN |

**To do:** put the 3.3 V load budget into a table (`docs/power-tree.md`) and place
a thermal via array under the LDO. If the number of externally powered devices
is going to grow, consider a switching regulator instead — but then the IMU
needs an LC filter plus a low-noise LDO stage so switching noise stays out of it.

### 6.5 The battery voltage divider is off-board

The `Battery_Voltage` net runs from J8 straight to PC3; the board carries only
C29 (0.1 µF) and no divider resistors. The divider is expected externally.

**Things to watch:**
- The STM32F4 ADC wants a low source impedance for 12-bit accuracy (up to about
  50 kΩ with a long sampling time, but under 10 kΩ is the safe answer).
- PC3 = ADC1_IN13, PC2 = ADC1_IN12 — correctly noted on the schematic.
- **There is no overvoltage protection.** If the divider is miscalculated or the
  external cable fails, something above 3.3 V goes straight into an MCU pin.
  Recommendation for Rev B: a 1 kΩ series resistor into PC3 plus a Schottky
  clamp to 3.3 V.

### 6.6 SBUS is not supported unless you add hardware

The block diagram mentions an "S-BUS Connector", but the **STM32F405's UARTs
have no hardware signal inversion** (the F7/H7 do; the F4 does not), and SBUS is
an inverted signal.

- **Using CRSF / ELRS:** no problem, CRSF is not inverted and J10 is ready.
- **Using SBUS:** you need an external inverter on the board (one NPN and two
  resistors, or a 74LVC1G04). Rev A does not have one.

### 6.7 Smaller notes

- **⚠ LD1/LD2/LD3 on PC13/PC14/PC15 — check the LED polarity.** These three pins
  sit in the backup power domain and are fed through an internal power switch.
  The STM32F405 datasheet is explicit about them: their total current is limited
  to **3 mA for all three combined**, they must not be driven above 2 MHz, and
  **they must not be used as a current source — the datasheet names driving an
  LED as the example.** In the Rev A schematic the LEDs are wired
  pin → LED → 1 kΩ → GND, which is exactly the sourcing configuration the
  datasheet warns against, and at ~1.3 mA each, two lit at once already consumes
  the budget for all three.

  Two fixes, both cheap:
  1. **Flip the LEDs to sink** — anode to +3.3 V, cathode through the resistor to
     the pin, driven low to light. No extra parts, just a schematic change, and
     it turns a forbidden configuration into an allowed one. Firmware logic
     inverts.
  2. **Move LEDs to PC0/PC1** — both are unused normal I/Os in the current
     pinout, with no backup-domain restriction. Two of the three LEDs could
     move there for free.

  Recommendation: do both — move two LEDs to PC0/PC1 and flip whatever stays on
  PC13–PC15 to sink configuration. Also note that using PC14/PC15 means **no LSE
  crystal can be fitted** (the RTC runs from the internal LSI only), which is
  irrelevant for a flight controller.
- **Crystal load capacitors.** C13/C14 = 10 pF, R1 = 0 Ω. Load capacitance is
  chosen as `C = 2 × (CL − C_stray)`; assuming C_stray ≈ 3–5 pF, 10 pF
  corresponds to a crystal with CL ≈ 7–7.5 pF. Verify the CL of the crystal you
  actually chose. R1 = 0 Ω is a placeholder for now — measure the drive level and
  replace it with something in the 47–220 Ω range if needed.
- **VDDA filtering is correct:** FB1 (600 Ω @ 100 MHz) + C15 (0.1 µF) + C16
  (1 µF). On LQFP64, VREF+ is bonded internally to VDDA — there is no separate
  pin, which matches the schematic.
- **VCAP1/VCAP2 = 2.2 µF** ✓ the value ST requires.
- **The BOOT0 switch (S2)** is SPDT, so BOOT0 is never left floating — correct.
- **Flash /HOLD and /WP** pulled to 3.3 V through 10 kΩ ✓.
- **USB protection:** USBLC6-2SC6 + polyfuse + 5.1 kΩ CC resistors ✓ correct.
- **IIS2MDC C1 pin** decoupled with 220 nF to GND ✓ as the datasheet requires.
- **Unused pins:** PA15, PB0, PB3, PB6, PB7, PC0, PC1, PC5 — listed with their
  options in §1.1. PB0 and PC5 are worth calling out: together they are exactly
  what a second IMU would need (a chip select and an interrupt line), so if
  redundancy comes back on the table in Rev B, the pins are already free.

---

## 7. Proposed firmware task architecture

This does not need an RTOS; prioritised interrupts plus a super-loop are
sufficient and have more predictable timing.

| Rate | Task | Trigger |
|---|---|---|
| 1.6 kHz | IMU read + filtering | IMU INT1 → EXTI |
| 1 kHz | PID → mixer → DShot | IMU read counter (÷n) |
| 1 kHz | Attitude estimation (Mahony/Madgwick) | Same chain |
| 100 Hz | Baro + mag state machine | SysTick counter |
| 100 Hz | ADC (battery, current) | SysTick |
| 50 Hz | RC packet processing (CRSF) | UART4 DMA IDLE |
| 10 Hz | GPS parsing (UBX/NMEA) | USART2 DMA IDLE |
| 10 Hz | Telemetry transmission | SysTick |
| 1 kHz | Blackbox enqueue | From the PID loop |
| Idle | Blackbox flush to flash, pre-erase | Main loop |

**The safety layer — non-negotiable:**

- **IWDG (independent watchdog)**, ~50 ms timeout, fed **only** by the main
  control loop. If the PID chain stops, the board resets and the motors stop.
- **Gyro timeout:** if N consecutive samples fail to arrive (the INT line goes
  quiet) → immediate disarm.
- **RC timeout:** ~500 ms with no packet → failsafe (progressive throttle cut,
  or return-to-home if GPS is available).
- **Arming interlock:** motors are **always** disarmed at power-up; arming
  requires low throttle plus an explicit arm command plus a sensor health check.
- **DShot pins after reset:** GPIOs are high-impedance at MCU reset. Confirm the
  ESCs do not apply throttle in that state; add pull-down resistors on the motor
  lines in Rev B if they do.

---

## 8. Decision summary

| # | Decision | One-line rationale |
|---|---|---|
| D1 | IMU alone on SPI1 | One read takes 388 µs on I²C — 39 % of the bus at 1 kHz, impossible at 8 kHz |
| D2 | Baro + mag share I2C2 | Combined bus load 4 %; neither is on the critical path, so their failure does not end the flight |
| D3 | External I²C on its own bus (I2C1) | A cable means ESD, capacitance and lockup risk — isolate the internal sensors from it |
| D4 | Flash on its own SPI (SPI2) | A sector erase can take 400 ms and must never delay a gyro read |
| D5 | Motors on TIM8, not TIM3 | Resolves the PB4/PB5 pin conflict; the 168 MHz timer clock doubles DShot resolution |
| D6 | DShot600 | No calibration, CRC-protected, 26.7 µs frame — a digital guarantee in a noisy environment |
| D7 | No bidirectional DShot in v1 | ESC firmware dependency plus painful debugging; get it flying first |
| D8 | ADC without DMA | ADC1's streams are taken; two channels at 100 Hz in an interrupt is negligible |
| D9 | I²C driver as a non-blocking state machine | An I²C lockup must never stall the control loop |
| D10 | Interrupt-driven sampling, not polling | Constant latency = correct timestamps = correct fusion |

---

## 9. Next steps

1. **Fix the LED drive on PC13–PC15** (§6.7) — the one item here that is an
   actual datasheet violation rather than a preference. Flip to sink
   configuration and/or move two LEDs to the unused PC0/PC1.
2. **Record the 1 kHz target loop rate in `README.md`** (§5.1) — the ODR ceiling
   and the anti-alias behaviour are now confirmed from the datasheet; what
   remains is making sure the gyro is initialised in **Low-Noise Mode** with
   `GYRO_UI_FILT_BW` set deliberately, and writing that into the IMU driver as a
   commented requirement rather than a bare register value.
3. **Revisit the I2C1 pull-ups** (§2.5) — 4.7 kΩ → 2.2 kΩ for the cabled bus.
4. **Decide SBUS vs CRSF** (§6.6); if SBUS, an inverter has to go on the board.
5. **Add battery-sense protection** (§6.5) — 1 kΩ series into PC3 plus a clamp.
6. **Create `docs/power-tree.md`** — the 3.3 V load budget and the LDO thermal
   calculation (§6.4).
7. **Derive `board.h` from §1.1** — do not maintain the pin map in two places.
8. **Firmware bring-up order:** SWD + LED blink, then raw IMU reads over SPI1,
   then DShot output (props off!), then closed loop.

---

*Document revision 1.2 · 2026-08-24 · Sources: MiniTULPAR Rev A schematic
(2026-08-10) and the current CubeMX pin configuration; STM32F405 datasheet and
the RM0090 reference manual; TDK ICM-42670-P datasheet DS-000451 (ODR range,
AAF behaviour, 24 MHz SPI / 1 MHz I²C limits and FIFO size verified against it).*
*DMA stream/channel assignments follow RM0090 Tables 42/43; verify them against
the reference manual once the final pin and peripheral selections are frozen.*

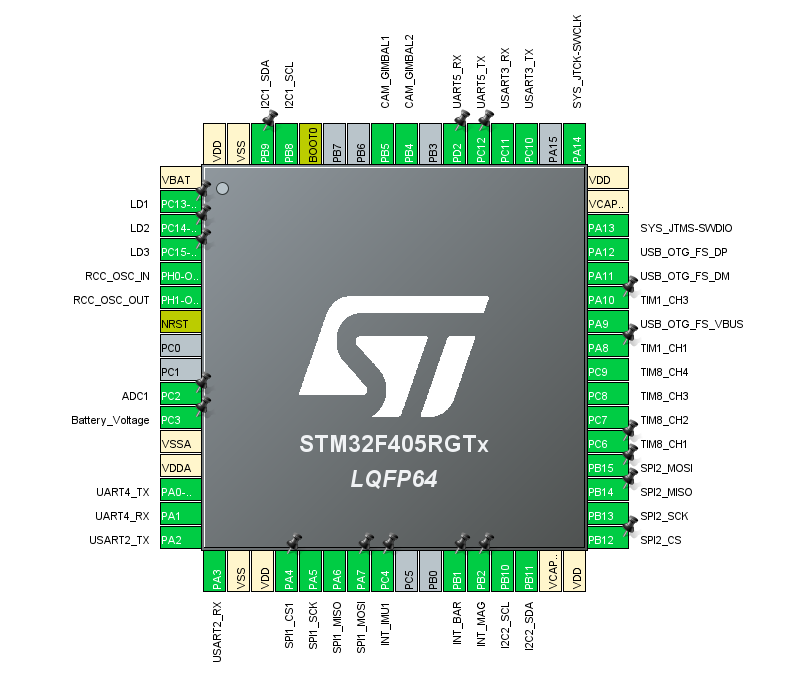
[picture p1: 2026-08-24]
docs/images/Pinout.png

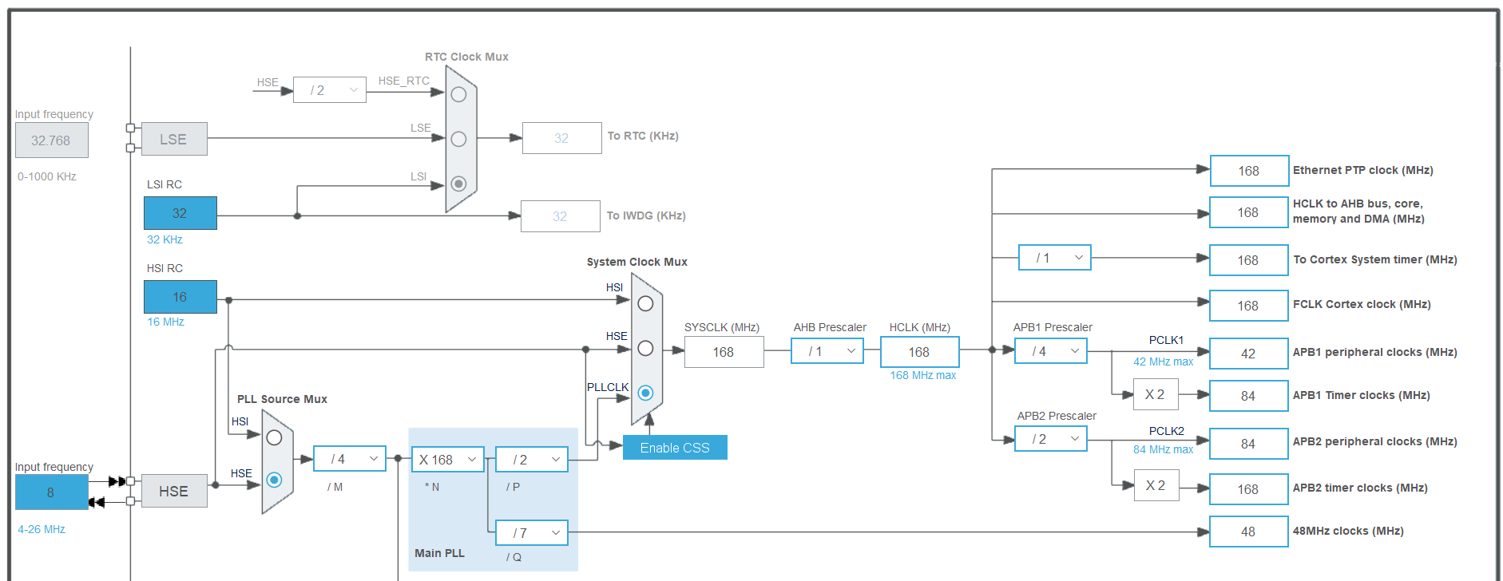
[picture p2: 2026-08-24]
docs/images/ClockConf.png

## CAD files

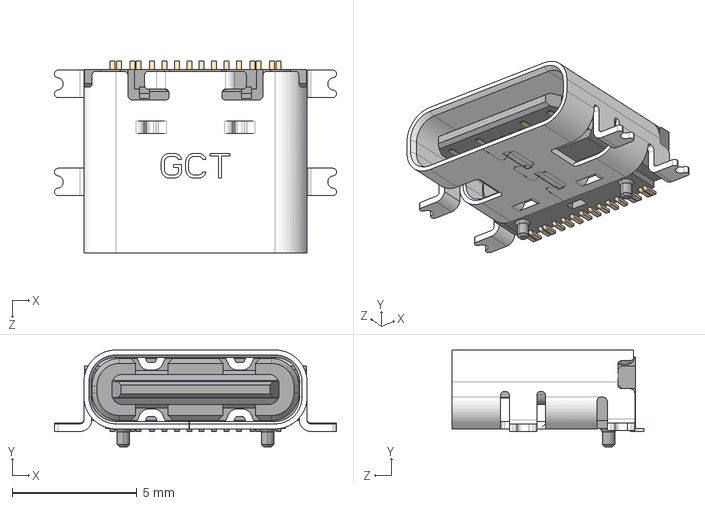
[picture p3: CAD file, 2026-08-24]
hardware/STEPFILE/USB4110-GF-A--3DModel-STEP-269445.STEP
11.3 x 3.89 x 7.70 mm

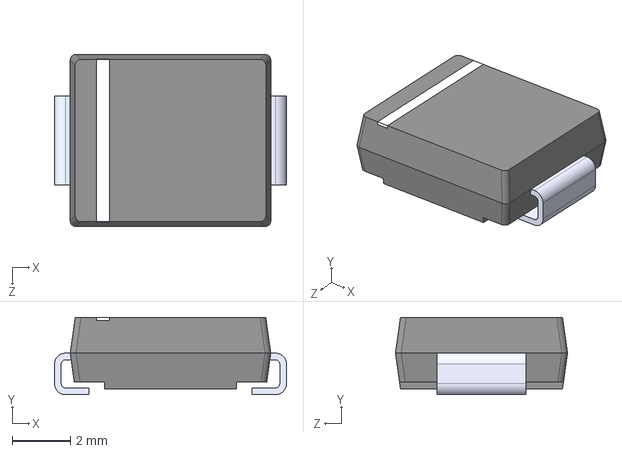
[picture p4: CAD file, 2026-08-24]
hardware/STEPFILE/SS34.STEP
7.95 x 2.65 x 5.90 mm

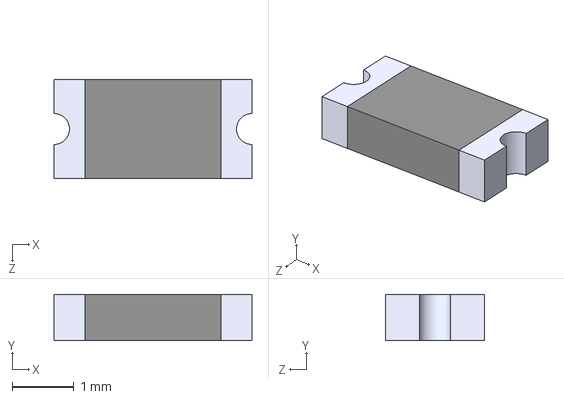
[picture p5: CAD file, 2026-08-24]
hardware/STEPFILE/polyfuse.STEP
3.20 x 0.75 x 1.60 mm

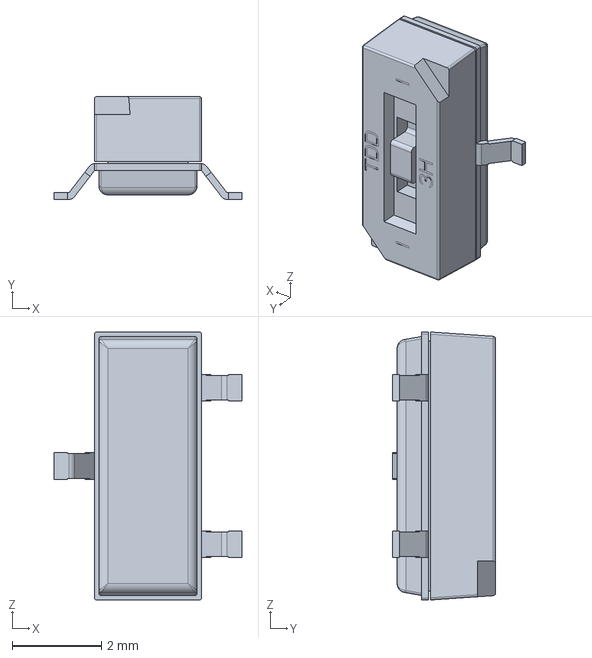
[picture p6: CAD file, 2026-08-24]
hardware/STEPFILE/TDD01H0SB1R.stp
4.20 x 2.30 x 6.00 mm

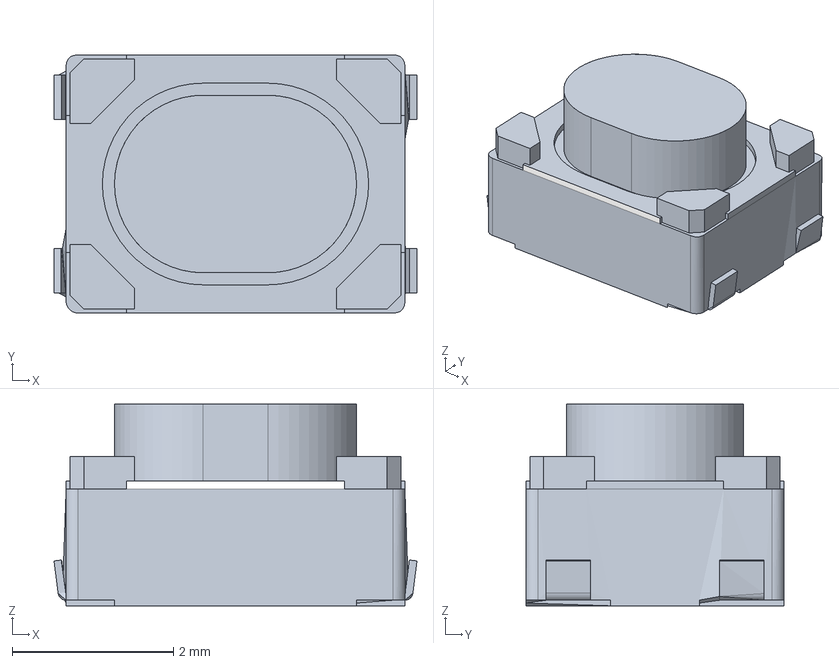
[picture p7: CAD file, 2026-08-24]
hardware/STEPFILE/PTS815SJM250SMTRLFS.stp
4.50 x 3.20 x 2.50 mm
PTS815SJM250SMTRLFS_PART1
PTS815SJM250SMTRLFS_PART2
PTS815SJM250SMTRLFS_PART3

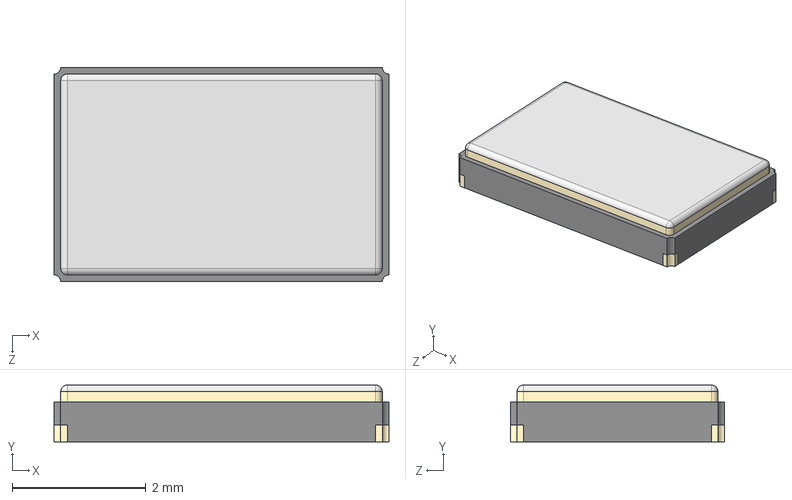
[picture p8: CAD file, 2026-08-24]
hardware/STEPFILE/ECS-80-10-30B-CKM-TR.step
5.00 x 0.85 x 3.20 mm

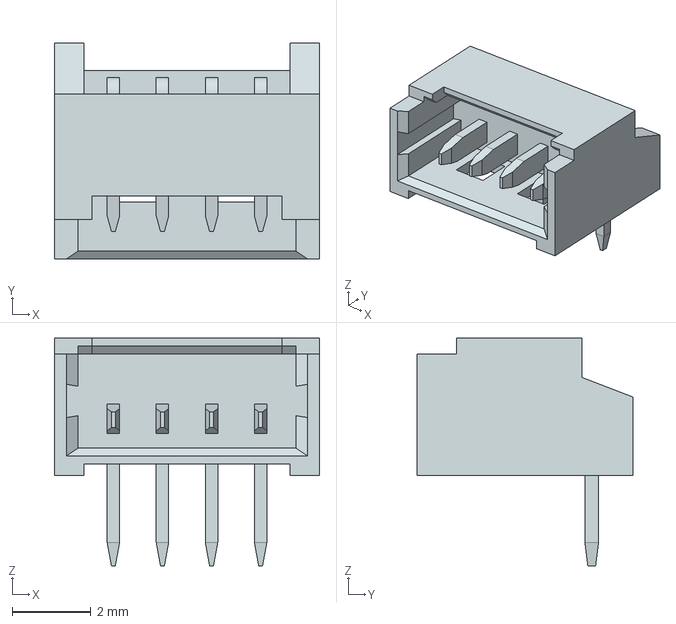
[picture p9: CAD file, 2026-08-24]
hardware/STEPFILE/530480410.stp
6.75 x 5.50 x 5.80 mm

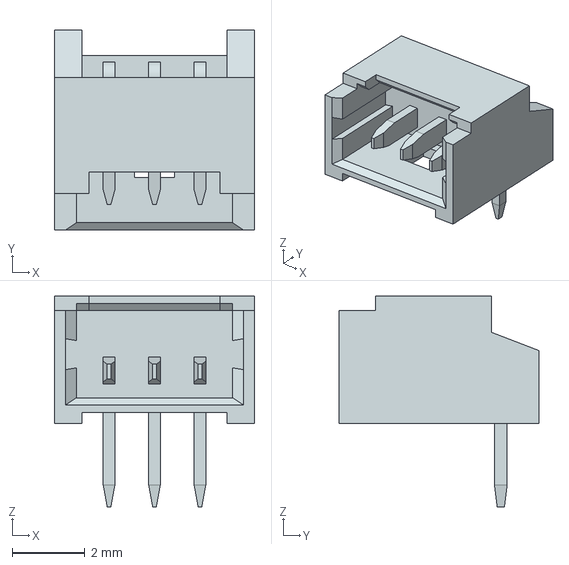
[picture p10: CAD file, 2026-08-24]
hardware/STEPFILE/530480310.stp
5.50 x 5.50 x 5.80 mm

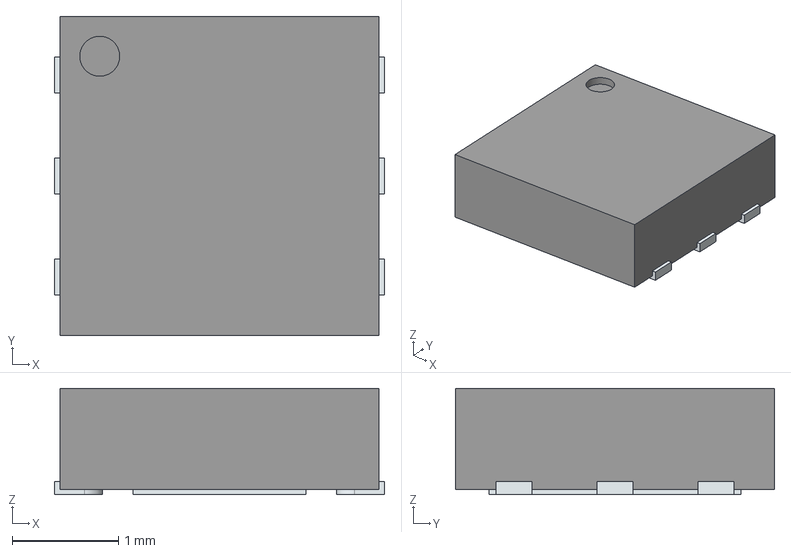
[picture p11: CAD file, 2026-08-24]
hardware/STEPFILE/LD39200PU33R.stp
3.10 x 3.00 x 1.00 mm
ThermalPin
PinsArrayLR

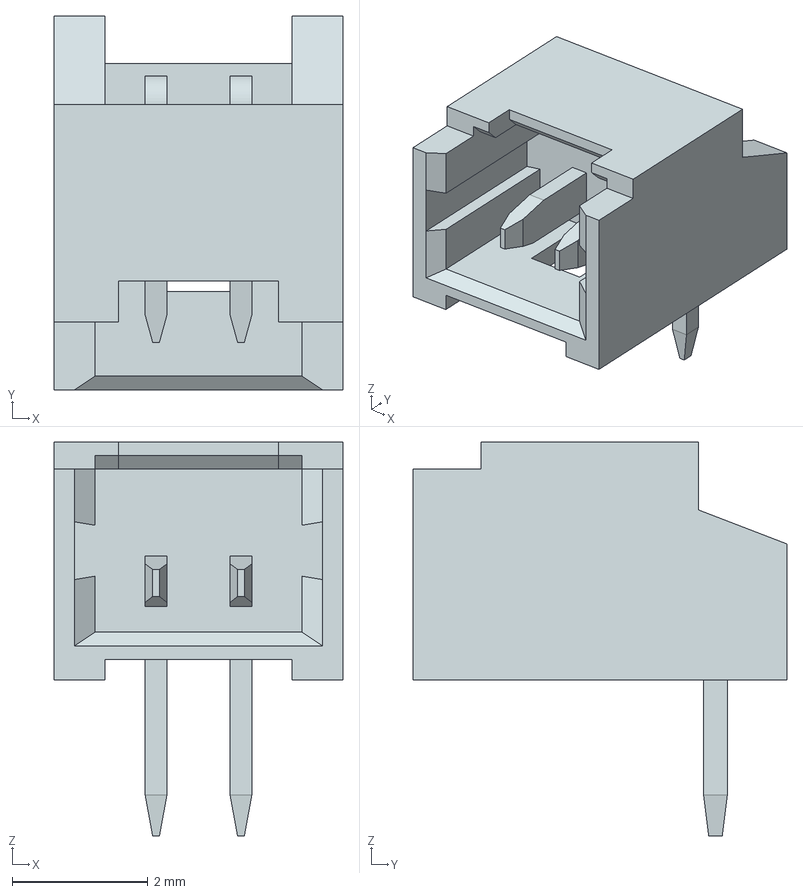
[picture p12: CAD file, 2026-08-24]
hardware/STEPFILE/530480210.stp
4.25 x 5.50 x 5.80 mm

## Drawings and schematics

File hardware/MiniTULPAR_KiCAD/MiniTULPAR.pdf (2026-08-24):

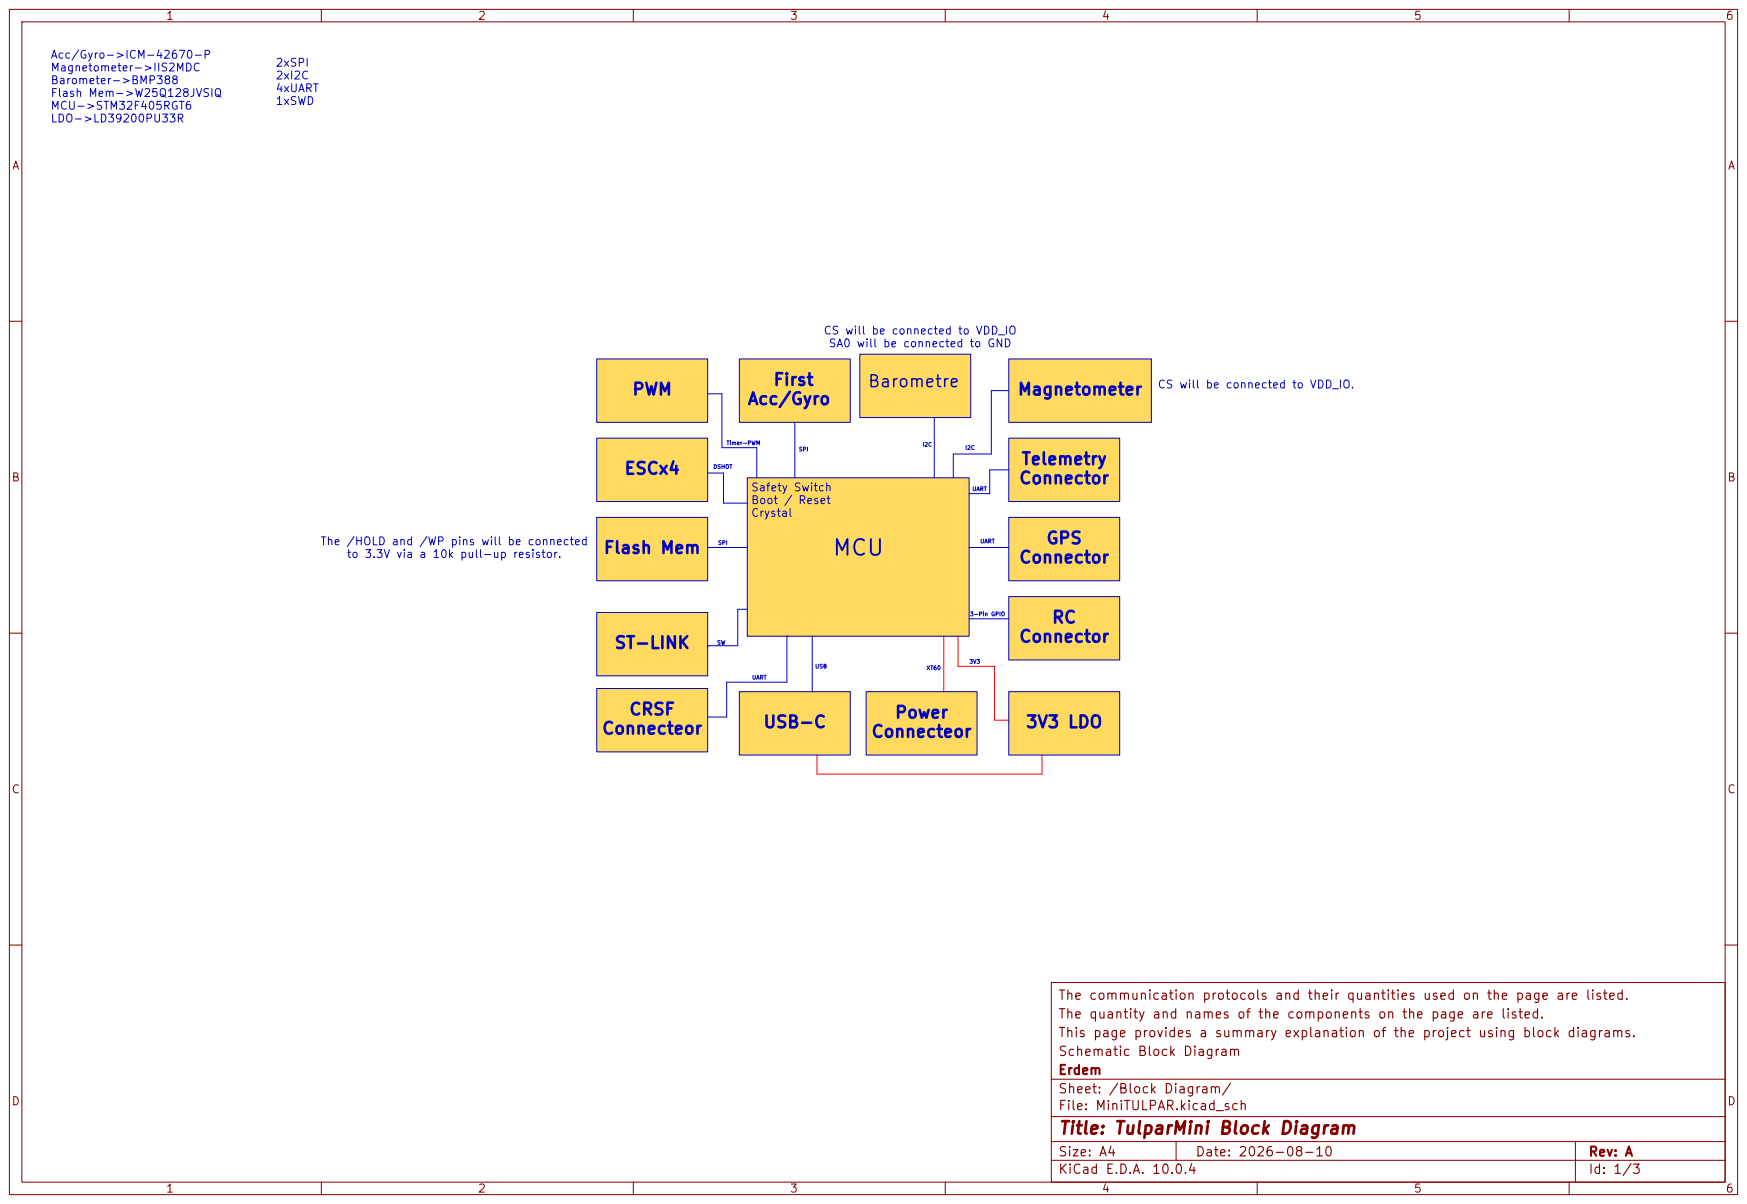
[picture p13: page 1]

to 3.3V via a 10k pull-up resistor. 2xSPI 2xI2C

SA0 will be connected to GND

CS will be connected to VDD_IO. Telemetry
Magnetometer

Safety Switch Boot / Reset Crystal

The /HOLD and /WP pins will be connected

The communication protocols and their quantities used on the page are listed.
The quantity and names of the components on the page are listed.
This page provides a summary explanation of the project using block diagrams.
Schematic Block Diagram
Erdem
Sheet: /Block Diagram/
File: MiniTULPAR.kicad_sch
Title: TulparMini Block Diagram

Size: A4 | Rev: A
KiCad E.D.A. 10.0.4 | Id: 1/3

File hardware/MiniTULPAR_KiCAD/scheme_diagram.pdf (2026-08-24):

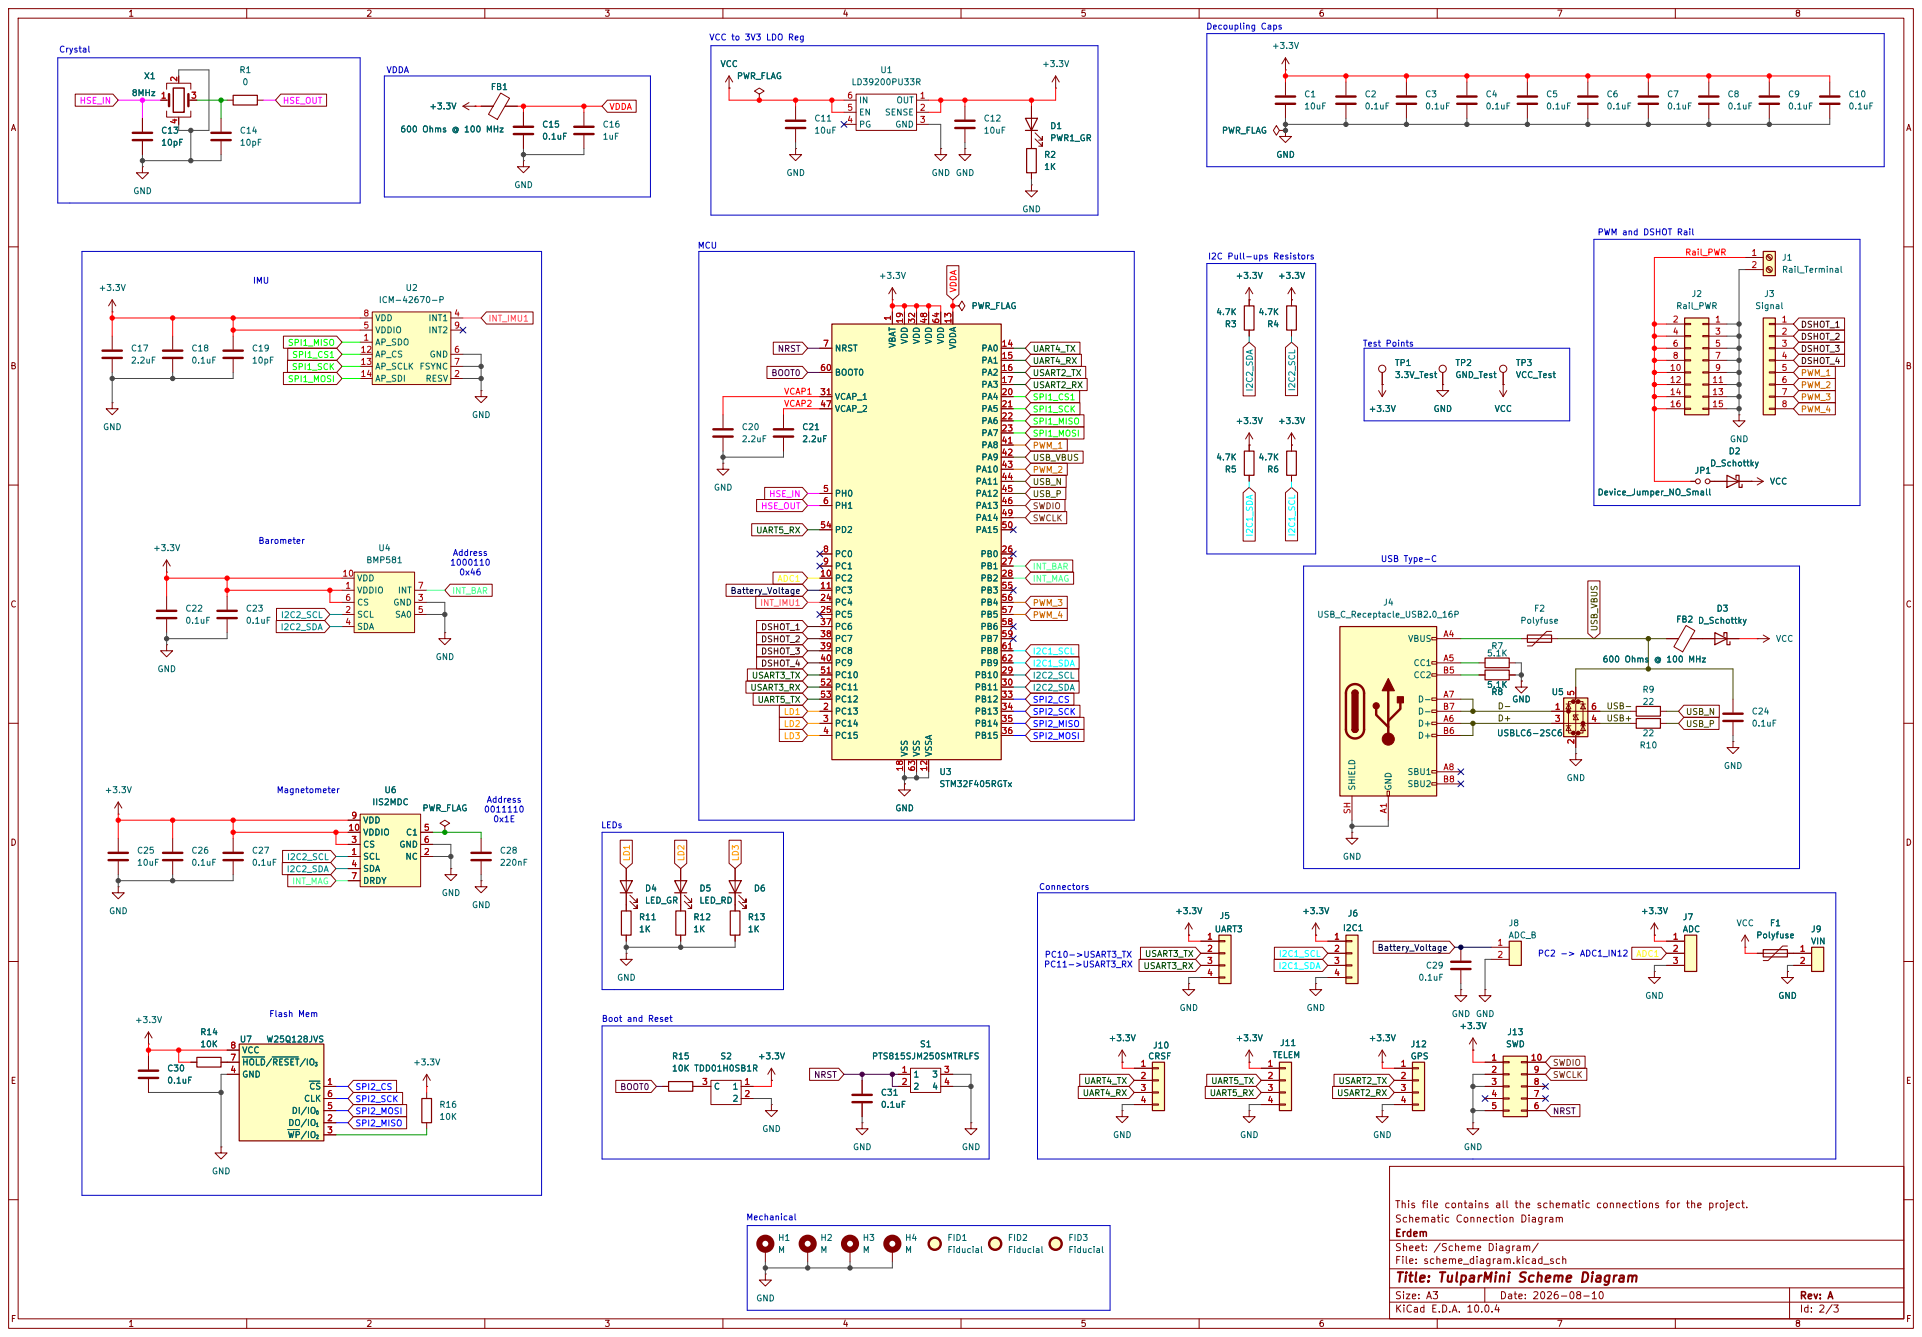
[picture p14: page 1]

VCC to 3V3 LDO Reg

PWM and DSHOT Rail

This file contains all the schematic connections for the project. GND

Schematic Connection Diagram
Erdem
Sheet: /Scheme Diagram/
File: scheme_diagram.kicad_sch
Title: TulparMini Scheme Diagram

Size: A3 | Rev: A | F Date: 2026-08-10
KiCad E.D.A. 10.0.4 | Id: 2/3

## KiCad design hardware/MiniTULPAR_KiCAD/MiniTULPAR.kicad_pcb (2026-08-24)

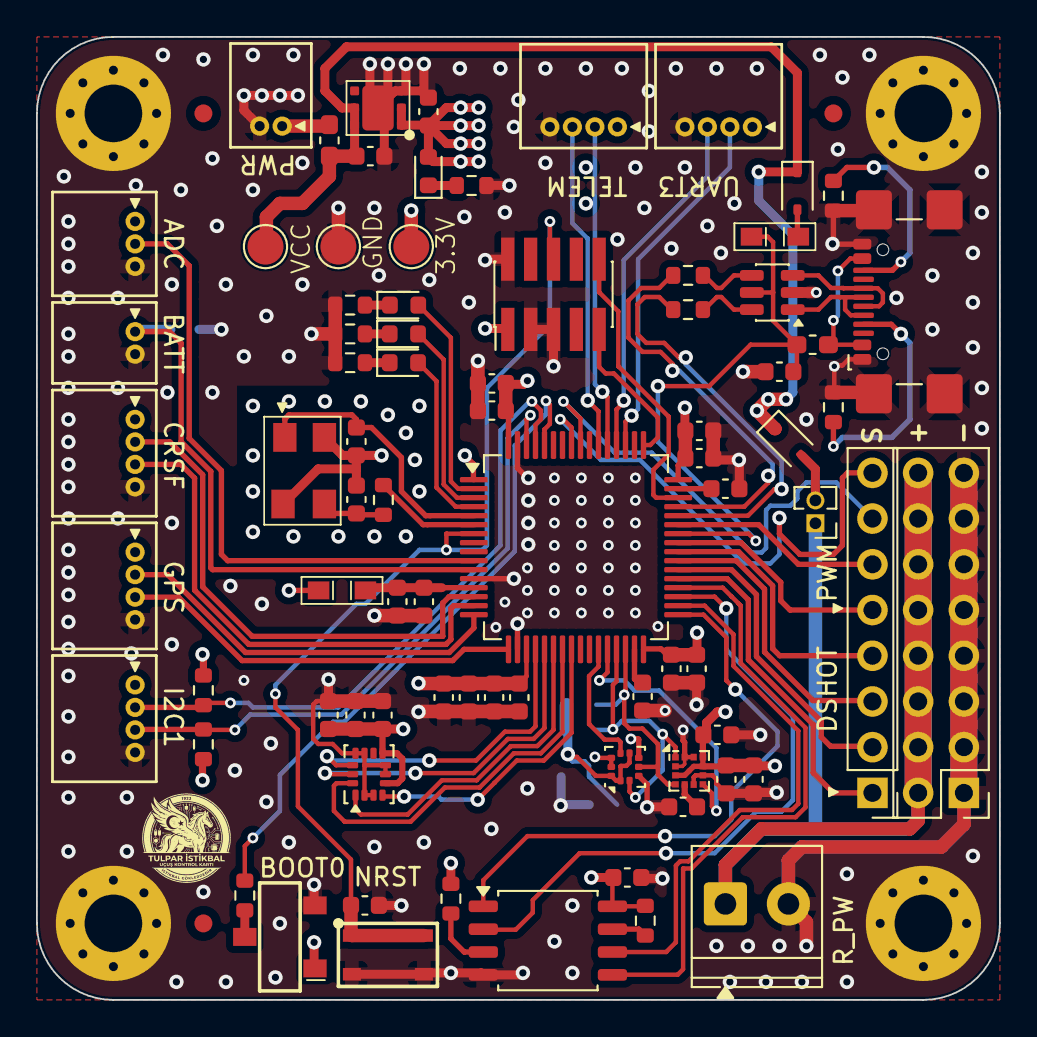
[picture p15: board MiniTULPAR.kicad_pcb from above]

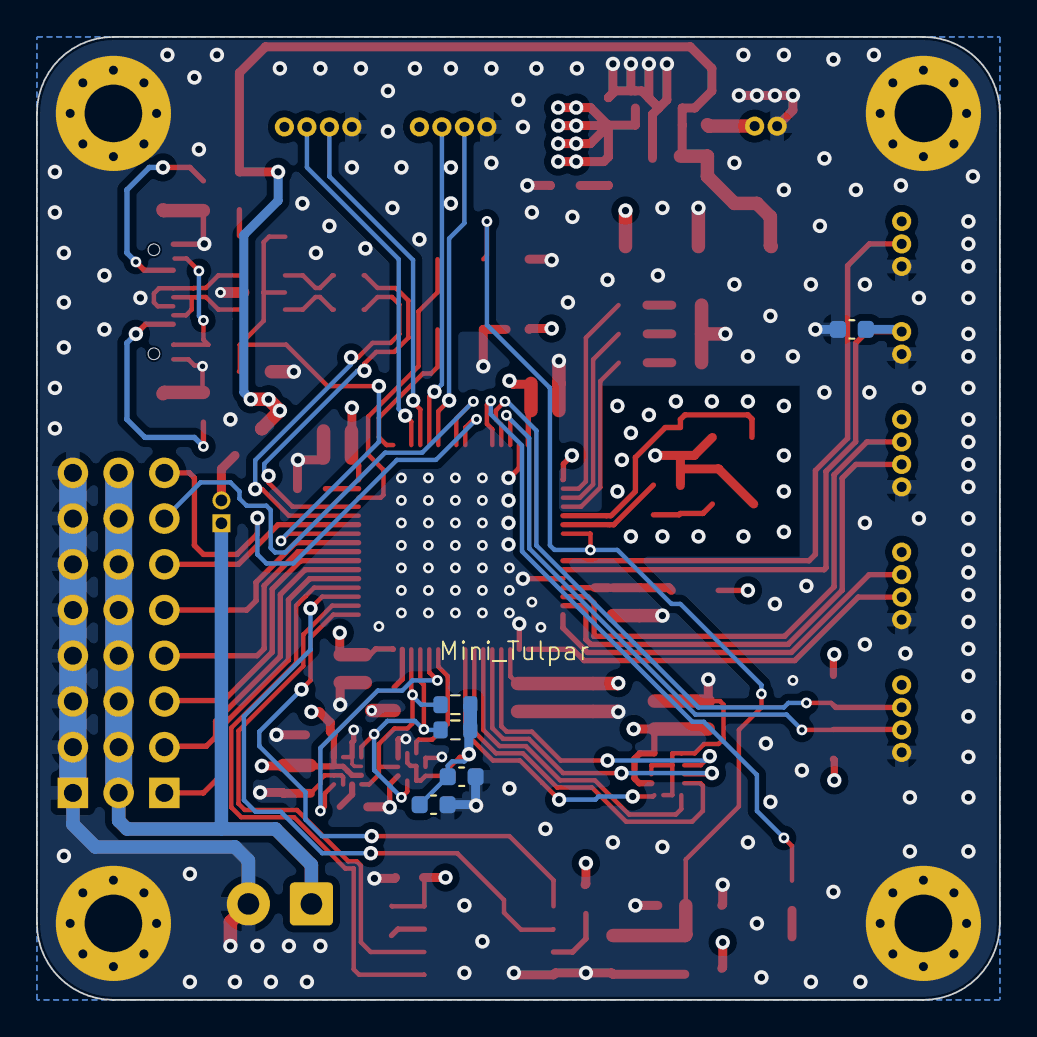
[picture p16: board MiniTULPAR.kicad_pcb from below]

Board: 4 copper layers, 53.5 x 53.5 mm, 91 parts (5 on the bottom side), 71 nets.

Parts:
C1, C11, C12, C25: 10uF; C_0603_1608Metric
C2, C3, C4, C5, C6, C7, C8, C9, C10, C15, C18, C22, C23, C24, C26, C27, C29, C30, C31: 0.1uF; C_0603_1608Metric
C13, C14, C19: 10pF; C_0603_1608Metric
C16: 1uF; C_0603_1608Metric
C17, C20, C21: 2.2uF; C_0603_1608Metric
C28: 220nF; C_0603_1608Metric
D1: PWR1_GR; LED_0603_1608Metric
D2, D3: D_Schottky; D_SOD-323
D4: LED_GR; LED_0603_1608Metric
D5: LED_RD; LED_0603_1608Metric
D6: LED_YE; LED_0603_1608Metric
F1, F2: Polyfuse; Fuse_0603_1608Metric_Pad1.05x0.95mm_HandSolder
FB1, FB2: 600 Ohms @ 100 MHz; MPZ2012S601AT000
FID2, FID4, FID5: Fiducial; Fiducial_1mm_Mask2mm
H1: M1; MountingHole_3.2mm_M3_Pad_Via
H3: M2; MountingHole_3.2mm_M3_Pad_Via
H5: M3; MountingHole_3.2mm_M3_Pad_Via
H8: M4; MountingHole_3.2mm_M3_Pad_Via
J1: Rail_Terminal; TerminalBlock_Phoenix_PT-1,5-2-3.5-H_1x02_P3.50mm_Horizontal
J2: Rail_PWR; PinHeader_2x08_P2.54mm_Vertical
J3: Signal; PinHeader_1x08_P2.54mm_Vertical
J4: USB_C_Receptacle_USB2.0_16P; USB_C
J5: UART3; CONN04_530480410_MOL
J6: I2C1; CONN04_530480410_MOL
J7: ADC; CONN03_530480310_MOL
J8: ADC_B; CONN02_530480210_MOL
J9: VIN; CONN02_530480210_MOL
J10: CRSF; CONN04_530480410_MOL
J11: TELEM; CONN04_530480410_MOL
J12: GPS; CONN04_530480410_MOL
J13: SWD; PinHeader_2x05_P1.27mm_Vertical_SMD
JP1: Device_Jumper_NO_Small; PinHeader_1x02_P1.27mm_Vertical
R1: 0; R_0603_1608Metric
R2, R11, R12, R13: 1K; R_0603_1608Metric
R3, R4, R5, R6: 4.7K; R_0603_1608Metric
R7, R8: 5.1K; R_0603_1608Metric
R9, R10: 22; R_0603_1608Metric
R14, R15, R16: 10K; R_0603_1608Metric
S1: PTS815SJM250SMTRLFS
S2: TDD01H0SB1R
TP1: 3.3V_Test; TestPoint_Pad_D2.0mm
TP2: GND_Test; TestPoint_Pad_D2.0mm
TP3: VCC_Test; TestPoint_Pad_D2.0mm
U1: LD39200PU33R
U2: ICM-42670-P; LGA-14_3x2.5mm_P0.5mm_LayoutBorder3x4y
U3: STM32F405RGTx; LQFP-64_10x10mm_P0.5mm
U4: BMP581; ST_HLGA-10_2x2mm_P0.5mm_LayoutBorder3x2y
U5: USBLC6-2SC6; SOT-23-6
U6: IIS2MDC; LGA-12_2x2mm_P0.5mm
U7: W25Q128JVS; SOIC-8_5.3x5.3mm_P1.27mm
X1: 8MHz; ECS-80-10-30B-CKM-TR

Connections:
+3.3V: C1.1, C2.1, C3.1, C4.1, C5.1, C6.1, C7.1, C8.1, C9.1, C10.1, C12.1, C17.1, C18.1, C19.1, C22.1, C23.1, C25.1, C26.1, C27.1, C30.1, D1.2 (A), FB1.1, J5.1, J6.1, J7.1, J10.1, J11.1, J12.1, J13.1, R3.2, R4.2, R5.2, R6.2, R14.1, R16.2, S2.1, TP1.1 (1_1), U1.1 (OUT), U1.2 (SENSE), U2.5 (VDDIO), U2.8 (VDD), U3.1 (VBAT), U3.19 (VDD), U3.32 (VDD), U3.48 (VDD), U3.64 (VDD), U4.1 (VDDIO), U4.6 (CS), U4.10 (VDD), U6.3 (CS), U6.9 (VDD), U6.10 (VDDIO), U7.8 (VCC)
/Scheme Diagram/D+: J4.A6 (D+), J4.B6 (D+), U5.3 (I/O2)
/Scheme Diagram/D-: J4.A7 (D-), J4.B7 (D-), U5.1 (I/O1)
/Scheme Diagram/Rail_PWR: J1.1, J2.2, J2.4, J2.6, J2.8, J2.10, J2.12, J2.14, J2.16, JP1.1
/Scheme Diagram/USB+: R10.2, U5.4 (I/O2)
/Scheme Diagram/USB-: R9.1, U5.6 (I/O1)
/Scheme Diagram/VCAP1: C20.1, U3.31 (VCAP_1)
/Scheme Diagram/VCAP2: C21.1, U3.47 (VCAP_2)
ADC1: J7.2, U3.10 (PC2)
BOOT0: R15.1, U3.60 (BOOT0)
Battery_Voltage: C29.1, J8.1, U3.11 (PC3)
DSHOT_1: J3.1, U3.37 (PC6)
DSHOT_2: J3.2, U3.38 (PC7)
DSHOT_3: J3.3, U3.39 (PC8)
DSHOT_4: J3.4, U3.40 (PC9)
GND: C1.2, C2.2, C3.2, C4.2, C5.2, C6.2, C7.2, C8.2, C9.2, C10.2, C11.2, C12.2, C13.2, C14.2, C15.2, C16.2, C17.2, C18.2, C19.2, C20.2, C21.2, C22.2, C23.2, C24.2, C25.2, C26.2, C27.2, C28.2, C29.2, C30.2, C31.2, H1.1 (1_1), H3.1 (1_1), H5.1 (1_1), H8.1 (1_1), J1.2, J2.1, J2.3, J2.5, J2.7, J2.9, J2.11, J2.13, J2.15, J4.A1 (GND), J4.A12 (GND), J4.B1 (GND), J4.B12 (GND), J4.SH (SHIELD), J5.4, J6.4, J7.3, J8.2, J9.2, J10.4, J11.4, J12.4, J13.2, J13.3, J13.5, R2.2, R7.2, R8.2, R11.2, R12.2, R13.2, S1.3, S1.4, S2.2, TP2.1 (1_1), U1.3 (GND), U1.7 (GND), U2.2 (RESV), U2.3 (RESV), U2.6 (GND), U2.7 (FSYNC), U2.10 (RESV), U2.11 (RESV), U3.12 (VSSA), U3.18 (VSS), U3.63 (VSS), U4.3 (GND), U4.5 (SA0), U4.8 (GND), U4.9 (GND), U5.2 (GND), U6.2 (NC), U6.6 (GND), U6.8 (GND), U6.11 (NC), U6.12 (NC), U7.4 (GND), X1.2 (G), X1.4 (G)
HSE_IN: C13.1, U3.5 (PH0), X1.1
HSE_OUT: R1.2, U3.6 (PH1)
I2C1_SCL: J6.2, R6.1, U3.61 (PB8)
I2C1_SDA: J6.3, R5.1, U3.62 (PB9)
I2C2_SCL: R4.1, U3.29 (PB10), U4.2 (SCL), U6.1 (SCL)
I2C2_SDA: R3.1, U3.30 (PB11), U4.4 (SDA), U6.4 (SDA)
INT_BAR: U3.27 (PB1), U4.7 (INT)
INT_IMU1: U2.4 (INT1), U3.24 (PC4)
INT_MAG: U3.28 (PB2), U6.7 (DRDY)
LD1: D4.2 (A), U3.2 (PC13)
LD2: D5.2 (A), U3.3 (PC14)
LD3: D6.2 (A), U3.4 (PC15)
NRST: C31.1, J13.6, S1.1, S1.2, U3.7 (NRST)
unnamed: C14.1, R1.1, X1.3
unnamed: D1.1 (K), R2.1
unnamed: D2.2 (A), JP1.2
unnamed: D3.2 (A), FB2.2
unnamed: D4.1 (K), R11.1
unnamed: D5.1 (K), R12.1
unnamed: D6.1 (K), R13.1
unnamed: F2.1, J4.A4 (VBUS), J4.A9 (VBUS), J4.B4 (VBUS), J4.B9 (VBUS)
unnamed: J4.A5 (CC1), R7.1
unnamed: J4.B5 (CC2), R8.1
unnamed: F1.2, J9.1
unnamed: R15.2, S2.3 (C)
unnamed: C28.1, U6.5 (C1)
unnamed: R14.2, U7.7 (~HOLD/~RESET/IO_{3})
unnamed: R16.1, U7.3 (~WP/IO_{2})
PWM_1: J3.5, U3.41 (PA8)
PWM_2: J3.6, U3.43 (PA10)
PWM_3: J3.7, U3.56 (PB4)
PWM_4: J3.8, U3.57 (PB5)
SPI1_CS1: U2.12 (AP_CS), U3.20 (PA4)
SPI1_MISO: U2.1 (AP_SDO), U3.22 (PA6)
SPI1_MOSI: U2.14 (AP_SDI), U3.23 (PA7)
SPI1_SCK: U2.13 (AP_SCLK), U3.21 (PA5)
SPI2_CS: U3.33 (PB12), U7.1 (~CS)
SPI2_MISO: U3.35 (PB14), U7.2 (DO/IO_{1})
SPI2_MOSI: U3.36 (PB15), U7.5 (DI/IO_{0})
SPI2_SCK: U3.34 (PB13), U7.6 (CLK)
SWCLK: J13.9, U3.49 (PA14)
SWDIO: J13.10, U3.46 (PA13)
UART4_RX: J10.3, U3.15 (PA1)
UART4_TX: J10.2, U3.14 (PA0)
UART5_RX: J11.3, U3.54 (PD2)
UART5_TX: J11.2, U3.53 (PC12)
USART2_RX: J12.3, U3.17 (PA3)
USART2_TX: J12.2, U3.16 (PA2)
USART3_RX: J5.3, U3.52 (PC11)
USART3_TX: J5.2, U3.51 (PC10)
USB_N: R9.2, U3.44 (PA11)
USB_P: R10.1, U3.45 (PA12)
USB_VBUS: C24.1, F2.2, FB2.1, U3.42 (PA9), U5.5 (VBUS)
VCC: C11.1, D2.1 (K), D3.1 (K), F1.1, TP3.1 (1_1), U1.5 (EN), U1.6 (IN)
VDDA: C15.1, C16.1, FB1.2, U3.13 (VDDA)

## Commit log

2026-08-24 docs: power tree, pinout and architecture notes
2026-08-24 hw: KiCad project and libs file
    [530480210.stp, 530480310.stp, 530480410.stp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]
2026-08-24 Update README to remove 2-layer variant mention
    Removed mention of a 2-layer variant to cut fabrication cost.

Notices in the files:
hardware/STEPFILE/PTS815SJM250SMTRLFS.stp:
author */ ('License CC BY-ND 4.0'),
